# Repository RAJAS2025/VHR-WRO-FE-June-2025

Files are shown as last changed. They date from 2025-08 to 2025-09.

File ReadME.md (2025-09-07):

This repository contains the documentation for Team VHR team's robot for the 2025 World Robot Olympiad Future Engineers competition. 

## Table of Contents
* [The Team](#the-team-)
* [The Challenge](#the-challenge-)
* [Photos of our Robot](#photos-of-our-robot)
* [Performance Video](#video)
* [Mobility Management](#mobility-management-)
  * [Chassis](#chassis)
  * [Spur Gear](#spur-gear)
  * [Differential Gear](#differential-gear)
  * [Steering Connecting Bar](#steering-connecting-bar)
  * [Wheel Holders](#wheel-holdersleft-and-right)
  * [Distance Sensor Holders](#distance-sensor-holder)
  * [Assembly of Chassis](#assembly-of-chassis)
  * [Motors](#motors)
  * [Drivetrain and Chassis Design](#new-drivetrain--chassis-design)
    * [Old Drivetrain and Chassis Design](#old-drivetrain--chassis-design)
    * [Differences in Old and New Chassis](#differences-between-new-and-old-chassis)
    * [New Robot Steering](#new-robot-steering)
    * [Old Robot Steering](#old-robot-steering)
    * [Car Component Placement](#car-component-placement) 
* [Power and Sense Management](#power-and-sense-management-)
  * [Controller](#controller)
  * [Battery](#battery)
  * [Sensing](#sensing)
  * [Gyro](#mpu-6050-3-axis-accelerometer--gyroscope)
  * [Camera](#huskylens-ai-vision-sensor)
  * [Schematics](#schematics-)
  * [Energy Consumption Breakdown](#energy-consumption-breakdown)
  * [Circuit Diagram](#circuit-diagram)
* [Obstacle Management](#obstacle-management-)
  * [Open Challenge Strategy and Code Explanation](#open-challenge-strategy-and-code-explanation)
  * [Obstacle Challenge Strategy and Code Explanation](#obstacle-challenge-strategy-and-code-explanation)
    * [Obstacle Challenge Turning Logic](#obstacle-challenge-turning-logic)
    * [Dodging Blocks](#dodging-blocks)
      * [Block Detection](#block-detection-huskylens)
      * [Adaptive Speed Control](#adaptive-speed-control)
      * [Block Dodging Algorithm](#block-dodging-algorithm)
      * [Steering and Gyro Function](#steering--wall-following-forward-function-obstacle)
    * [Parallel Parking](#parallel-parking)
* [Robot Assembly Guide](#assembly-guide)
* [Cost Report](#cost-report)
  * [Parts Cost](#part-cost)
  * [Parts BOM](#parts-bill-of-materials-bom)
* [Special Thanks](#special-thanks)

---

# The Team 

### Team photo
 
<br>
(Harshad, Vishnu, Rajas)

<br>

### Harshad Mahajan

<b>Age:</b> 15

<b>High School:</b> John Fraser Secondary School

<b>Description:</b> Hi! I’m Harshad. This is my first season in WRO. Last year I took part in the Zone_01 category, and this year I wanted to challenge myself with something new. I’m interested in coding, building robots, and exploring creative ideas. I also enjoy sports and traveling.

---

### Vishnu Jayakumar

<b>Age:</b> 15

<b>High School:</b> John Fraser Secondary School

<b>Description:</b> Hello! I’m Vishnu. This is my third season in WRO and my first time competing in the Future Engineers category, after two seasons in WRO Junior. I’m passionate about robotics, electronics, and exploring new technologies, but I also enjoy basketball, math, and spending time with friends.

---

### Rajas Salunke

<b>Age:</b> 16

<b>High School:</b> Fletchers Meadows Secondary School

<b>Description:</b> Hello! I’m Rajas Salunke. This is my second season in WRO and my first in the Future Engineers category, after previously competing in WRO Junior. I’m passionate about building circuits and rockets, and I also enjoy hockey and calisthenics.

---

## The Challenge 

The **[WRO 2025 Future Engineers](https://wro-association.org/)** challenge is all about building an autonomous car that can adapt to a racetrack which changes every round. Instead of just speed, the focus is on control and problem-solving: the car needs to handle obstacles placed at random and also pull off a precise parallel park. It’s a mix of engineering and strategy, where teams combine sensors, algorithms, and creative design to make their car both smart and reliable.

This challenge emphasizes all aspects of the engineering process, including:
- **Movement:** Designing the vehicle to move efficiently and smoothly.
- **Obstacle Navigation:** Programming the car to detect and handle traffic markers within the rules.les.
- **Documentation:** Recording design decisions, progress, and collaborative work in a public GitHub repository.

Points are awarded based on how well teams perform in the challenge rounds, the thoroughness of their engineering documentation, and the creativity and reliability of their solutions. The aim is to inspire learning in STEM through hands-on robotics, collaborative teamwork, and inventive problem-solving.

To learn more about the challenge, click [here](https://wro-association.org/wp-content/uploads/WRO-2025-Future-Engineers-Self-Driving-Cars-General-Rules.pdf).

---

# Photos of our Robot

|  |  | 
| :--: | :--: |
| *Front* | *Back* |
|  |  | 
| *Left* | *Right* |
|  |  | 
| *Top* | *Bottom* |

---

# Video
Here is the link to our Obstacle Challenge: https://youtu.be/RuCk_0WW9Mc
<br>
Here is the link to our Open Challenge: https://youtu.be/YiaeHu-xXsg

--- 

# Mobility Management 

## Chassis

Our chassis is a fully custom-designed base, modeled in SolidWorks to create a compact and efficient structure optimized for sharp servo steering. On top of the chassis, we mounted our PCB, which holds the main electronics and three laser distance sensors—one at the front and one on each side—allowing the robot to sense walls and obstacles accurately. The motor is positioned beneath the PCB in a dedicated motor holder and drives a spur gear that connects to a reinforced LEGO differential, forming a robust drivetrain.

The front steering is designed for sharp, precise turns, giving the robot the ability to navigate tight corners and avoid obstacles efficiently. The chassis layout also ensures that the weight of the sensors and electronics is balanced over the drivetrain, improving stability and traction during high-speed maneuvers.

### Potential Chassis Improvements
An improvement we could make to our chassis is lowering the center of gravity even further. A lower center of gravity keeps the car’s weight closer to the ground, which improves stability and allows for quicker, more accurate steering at higher speeds. With reduced body roll, the tires maintain stronger grip on the road, giving the driver greater precision and control. As a result, the car feels more responsive during sharp turns, lane changes, and fast cornering.



### Spur Gear

To transfer power from the 6V motors to the modified LEGO differential, we designed and 3D-printed a 36-tooth spur gear that fits the motor’s 3mm D-shaped shaft and meshes precisely with the LEGO axle system. Using a 36-tooth input gear paired with a 24-tooth output gear, we geared the drivetrain for higher speed while taking advantage of the motor’s high torque and low RPM. This gear ensures smooth and efficient power transfer, providing consistent wheel rotation even under load.



### Differential Gear

The LEGO differential was imported from an online CAD model into SolidWorks and slightly reinforced to improve durability. Extra material was added around the mounting holes, and the differential was adapted to fit our custom chassis. These modifications maintain smooth power transfer to the wheels under high-torque operation, while reducing stress on the mounting points and improving overall reliability during obstacle navigation.



### Steering Connecting Bar

The steering connecting bar is a compact, custom-designed link optimized for our sharp servo steering system. Modeled in SolidWorks, it features recessed screw inlets for better grip and durability, ensuring a secure connection between steering components. Its lightweight design minimizes additional load while transferring motion smoothly, allowing the front wheels to respond precisely to steering commands even during tight turns.

 

### Wheel Holders(Left and Right)
The wheel holder was custom-designed in SolidWorks for our compact steering system. The extended cylinder secures a bearing for smooth tire rotation, while the smaller hole connects to the steering bar and the larger hole mounts to the chassis base.

 

### Distance Sensor Holder

The distance sensor holder combines a custom-made 4M LEGO beam with a secure TinkerCAD-designed mount to keep the TOF sensor rigid and stable. This eliminates vibration or shifting during operation, ensuring accurate and consistent sensor readings. The LEGO integration allows for easy attachment to the chassis while maintaining a locked position, supporting reliable obstacle detection and wall-following maneuvers.



### Assembly of Chassis

ezgif com-video-to-gif-converter (1)

## Motors

### 24mm Brushless DC Gear Motor
The robot's forward and backward propulsion is provided by a 24mm brushless DC gear motor. This motor was chosen for its ideal balance of high speed and torque. The brushless design makes it highly efficient, durable, and provides a smooth, consistent power delivery. This motor is the core of the drivetrain, ensuring reliable and powerful movement throughout the competition.



Here are the specifications: [Motor Specifications](https://drive.google.com/file/d/1moiPKcTiO8_0Bga1mJdIX5mgfcUgAj7J/view?usp=drive_link)

### Miuzei MG90S 9G Micro Servo Motor
The robot's steering mechanism is controlled by a Miuzei MG90S 9G Micro Servo Motor. A servo is a specialized motor designed for precise angular control rather than continuous rotation. This particular model was chosen for its metal gear construction, which offers greater durability and higher torque than plastic gear versions. The servo's ability to hold a specific angle is what allows the robot to make precise steering adjustments and navigate tight corners effectively.



Here are the specifications: [Servo Specifications](https://drive.google.com/file/d/1ZQCr9s1xJsN8NOYWgczae_1dq8hoC7bo/view?usp=drive_link)

## New Drivetrain & Chassis Design

Our robot is a four-wheeled vehicle that uses a **rear-wheel drive with sharp front-wheel servo steering**. The chassis was custom-modeled in SolidWorks for a compact, lightweight structure that minimizes complexity while maximizing reliability. By separating the steering system from the drivetrain, we avoided issues with spacing and ensured that the steering servo and the drive motors operate independently without interference. This gave us two possible configurations: front-wheel drive with rear steering or rear-wheel drive with front steering.  

We chose the **rear-wheel drive with front steering** configuration because it provides several advantages:

| Rear-Wheel Drive | Front-Wheel Drive |
| --- | --- |
|  |  |
| **Why we chose rear-wheel drive:** <br><br>- **More precise steering**, since the front wheels focus only on steering. <br>- **Balanced handling**, with weight distributed between front and rear. <br>- **No torque steer**, unlike front-wheel drive systems. <br>- **Stronger traction under acceleration**, as weight shifts to the rear drive wheels. <br>- **Better power handling**, making it suitable for higher torque motors. <br>- **Familiar control response**, matching our previous experience with other rear-driven LEGO robots. | **Why we avoided front-wheel drive:** <br><br>- Steering is less precise because the wheels also handle power delivery. <br>- Can cause **torque steer**, pulling the robot off-course under acceleration. <br>- Reduced traction at the rear wheels, especially when weight shifts forward during braking. <br>- Harder to balance power and steering without interference. <br>- Less efficient for handling higher torque loads. |

Overall, the **rear-wheel drive with front steering** configuration gave us the best balance of control, traction, and reliability. It allowed us to maximize precision while keeping the drivetrain simple and effective for competition.

---

The drivetrain works by transferring power from the rear motors into a 36-tooth spur gear that meshes with a 24-tooth gear, creating a 1.5:1 gear ratio. This gearing choice slightly increases speed while still maintaining enough torque to handle obstacles. From there, power flows into the differential gear, which splits torque between the two rear wheels so they can spin at different speeds during turns. This prevents skidding, reduces stress on the drivetrain, and keeps the robot’s motion smooth. The differential outputs directly to the rear wheels, giving strong and reliable traction. Meanwhile, the front wheels are connected to a servo motor that independently controls steering. Because the steering and drivetrain are separate, the robot achieves sharp, responsive turns without being affected by torque from the drive system.

## Old Drivetrain & Chassis Design

Our old robot also used a rear-wheel drive system with the same advantages. However, it was built mostly from LEGO pieces, making it bulkier and less optimized. The drivetrain design placed the motor vertically at the back, which consumed a lot of space.

| Back Photo of Motor | Side Photo of Motor |
| --- | --- |
|  |  |

## Differences between New and Old Chassis

In our new robot, the motor case is positioned beneath the battery holder, saving significant space and allowing for a more compact design. The gearing layout has also been updated: the new robot uses a side-to-side gearing configuration due to the use of spur gears, whereas the old robot had a downward setup due to the use of bevel gears. The old chassis was designed with space for gearing down to achieve more torque, while the new chassis supports either a 1:1 ratio (30-tooth spur to 30-tooth differential) or our current setup with a 36-tooth spur and 24-tooth differential. Additionally, the steering base in the new chassis is smaller and more compact, in contrast to the old design where the steering width spanned the entire chassis.

| Spur Gear View of Chassis | Differential Gear View of Chassis |
| --- | --- |
|  |  |

## New Robot Steering

Our steering system uses a four-bar linkage with free-spinning wheels on each side. A servo motor with an arm drives the four-bar, changing the wheel angles to steer the vehicle. This setup is lightweight, efficient, and easy to implement with minimal components.

The steering is managed by a Miuzei MG90S micro servo motor, which provides precise angular control. A standard servo arm drives a four-bar linkage, with free-spinning wheels on each side made from a bearing fitted with a tire. Each wheel is secured using a custom attachment that connects directly to the bearing. This lightweight and durable setup ensures quick, precise steering response, enabling the robot to execute sharp turns and navigate obstacles effectively. To save space, our steering is mounted in a reversed configuration: the four-bar sits behind the servo’s output, and the arm operates in the opposite direction.

ezgif com-speed (1)

## Old Robot Steering
In our previous robot, we employed the same steering concept, but the system was configured in a forward layout and was significantly larger and wider. The servo arm and mount were 3D printed as a single piece, featuring a LEGO axle–shaped cross hole that rotated in sync with the servo. Unlike the new design, the four-bar linkage was not 3D printed; it was constructed by connecting two LEGO beams with a LEGO wheel mounted on each side.

| Four-Bar Steering Mechanism |
| --------------------------- |
|  |

## Car Component Placement

The main chassis serves as the foundation of the car, housing most of the core components. On top of this base, additional parts such as VEX pieces, LEGO elements, and custom 3D-printed mounts are integrated to securely attach and support each component. More details about each specific electrical component can be found in power and sense management. 

| Part | Description | Image |
| --- | --- | --- |
| TOF Distance Sensors | • **Two-beam setup** for mounting<br>• **Double-sided beam** secured with two VEX star-drive screws<br>• **LEGO beam + frame** attached below VEX beam<br>• Frame offers **multiple connection points**<br>• TOF sensors mounted using **LEGO beams on their side**<br>• Allows **easy adjustment** and **quick fixes**<br>• Maintains overall **stability** |  |
| Husky Lens Camera | • Mounted on **two VEX standoffs**<br>• Standoffs fastened to **LEGO beams** with VEX screws<br>• Camera secured with **two M3 screws** on top beam<br>• Chosen over **3D-printed bracket** for flexibility<br>• **Adjustable height** by swapping standoffs<br>• Provides **rigidity and durability** |  |
| Battery | • Placed at **center of chassis CAD**<br>• **Dedicated slot** sized for battery fit<br>• **PCB mounted above** for short, direct connections<br>• Prevents **wire tangling**<br>• **Front cutout** allows space for servo motor integration |  |
| PCB | • Located **above battery slot**<br>• Space designed for **PCB with sensor ports**<br>• **Clear sides** for neat wire management<br>• **Rear hole** provides access to power button<br>• Supports clean and efficient wiring layout |  |
| Camera Lens | • Located **on camera**<br>• Added to widen camera view and see more blocks |  |

# Power and Sense Management   

## Controller

The robot uses an ESP32 microcontroller for fast processing and built-in Wi-Fi/Bluetooth. It handles everything from sensor input to motor control and wireless communication without slowing down. Its small size fits easily in the chassis, and low power use helps extend battery life — perfect for competition.

An image of a ESP32 controller

## Battery

The robot is powered by two 6-volt NiMH (Nickel-Metal Hydride) battery packs. We chose these batteries for their high current output, which is essential for reliably running all the electronics, including the motors, without performance drops. Their use also ensures the robot has enough capacity for longer operation periods, a key advantage during competition.

As rechargeable batteries, they provide a cost-effective and time-saving solution, as they don't need to be replaced after every use. Their compact size allows them to fit neatly inside the robot's chassis, which helps in maintaining a balanced and low-profile design.

An image of a NiMH battery pack

## Sensing

### VL53L0X Time-of-Flight (ToF) Distance Sensors

The robot uses three VL53L0X Time-of-Flight (ToF) distance sensors to measure the distance to surrounding objects. These sensors work by emitting a laser pulse and calculating the time it takes for the light to reflect back, providing highly accurate and reliable distance measurements in millimeters. The three sensors are strategically placed on the robot to provide multi-directional awareness for obstacle avoidance and maintaining a consistent distance from the walls. They are the primary tool for the robot's navigation on the track.

An image of a VL53L0X ToF distance sensor

### MPU-6050 3-Axis Accelerometer & Gyroscope

The MPU-6050 is used to monitor the robot's orientation and heading. The gyroscope provides real-time data on the robot's yaw, pitch, and roll. The robot primarily uses the yaw axis to track its heading and maintain accurate directional control. Before each use, the gyro is calibrated to ensure precision, and a starting reference angle is set to 0. This allows the robot to consistently track its orientation and make precise turns, such as a 90-degree turn, by adjusting the offset relative to its starting position. This sensor is crucial for ensuring the robot drives in a straight line and turns accurately.

An image of a MPU-6050 gyro sensor

### HuskyLens AI Vision Sensor
The HuskyLens is a powerful AI vision sensor that provides the robot with the ability to "see" and identify objects. It is pre-trained to recognize colors and objects, which is a key part of your strategy for the Obstacle Challenge. The robot uses the HuskyLens for several key functions:

- **Color Recognition:** It is trained to detect specific colors like red and green for identifying traffic blocks, pink for the parallel parking markers, and blue and orange lines to turn.

- **Object Positioning:** The sensor provides the x and y coordinates of the detected objects, which are directly used by the program to guide the robot's movements.
This sensor allows the robot to perform complex tasks like avoiding obstacles and executing precise maneuvers such as parallel parking.

An image of a Huskylens AI vision sensor

---

# Schematics 

This schematic provides a clear overview of the robot's electronic design. It shows how a central ESP32 microcontroller manages various sensors and motors, enabling autonomous navigation and obstacle avoidance. The design is modular, with a focus on efficient communication and power management.

A schematic of the robot's electronic components and connections

### Power Management
The robot's power is supplied by a 6V battery pack, which connects at CN1. This power is distributed to all components in two ways. A voltage regulator (U8) steps down the 6V to a stable 3.3V to safely power the ESP32 and other sensitive electronics. The 6V supply is also used directly to power the motors and servo, as they require higher voltage and current.

### Motors
The Miuzei MG90S 9G Micro Servo Motor (S1) connects to pin D32 on the board for its control signal. The 24mm Brushless DC Gear Motor connects to the board via its motor driver (not explicitly shown) to a GPIO pin for control. Both motors are powered by the external 6V supply

### Sensors

- **VL53L0X ToF Lidar Sensors (U2, U3, U4):** The three VL53L0X Lidar sensors (U2, U3, U4) connect to the board's I2C pins (SDA/SCL) via an I2C Multiplexer (U7).

- **I2C Multiplexer (U7) & I2C Expander (U5):** To manage the three Lidar sensors on a single I2C bus, an I2C Multiplexer is used to allow the microcontroller to communicate with each sensor individually. An I2C Expander is also included to provide additional I2C communication lines for other devices.

- **HuskyLens (UB):** The HuskyLens (UB) connects to the board's serial communication pins (RXD2/TXD2) to send data back and forth.

## Energy Consumption Breakdown

### Baseline (no motors)
- ESP32 + HuskyLens + MPU6050 + 3× ToF  
  - 120 + 230 = 350 mA  
  - 350 + 4 = 354 mA  
  - 354 + 60 = **414 mA**

### Typical Total (with motors + servo)
- Baseline: 414 mA  
- + DC motor (typical): +450 mA → 864 mA  
- + Servo (typical): +70 mA → **934 mA**

### Peak Load
- ESP32 peak: 260 mA  
- HuskyLens peak: 300 mA → 560 mA  
- + MPU6050: +4 mA → 564 mA  
- + ToF peaks: +120 mA → 684 mA  
- + Motor nominal: +450 mA → 1,134 mA  
- + Servo peak (70–140 mA): → **~1,204 mA**

### Worst-Case (stall currents)
- DC motor stall: 3× nominal → 450 × 3 = 1,350 mA  
- Servo stall: 2× → 70 × 2 = 140 mA  
- Non-motor peak subtotal: 684 mA  
- 684 + 1,350 + 140 = **≈ 2,174 mA (~2.17 A)**

---

**Summary:**  
- Typical draw ≈ **934 mA**  
- Peak ≈ **1.2 A**  
- Worst-case transient ≈ **2.2 A**

---

# Obstacle Management 

## Open Challenge: Strategy and Code Explanation

This program controls the robot using TOF sensors and a gyro to navigate by following the outer wall. When the robot detects a wall ahead, it chooses the clearer side by comparing right and left values, and stores it in side. From that point on, the robot consistently follows the chosen outer wall, using TOF readings and gyro correction to stay aligned. Because the outer wall distance is always fixed, this method remains reliable even if interior walls shift or move. A turn count tracks progress through the maze, and once it reaches 12, the robot stops wall-following and drives straight to the finish using gyro-based control.

| Straight Movement | Turning |
| --- | --- |
|  |  |

| Open Challenge Flowchart |
| ------------------------ |
|  |

### Robot Motion Control (Open)

This part of the repository contains control laws for straight driving using gyro correction and wall-following behaviors using TOF sensor + gyro fusion.  

#### Straight Driving (forward)

The `forward()` function maintains straight-line motion by applying gyro-based steering correction.
```ino
// Move forward while correcting steering based on gyro
void forward(float g) {
  angle = (int)(0.8 * (g - (offsetangle))); // Steering correction
  int pos = 95 - angle;                     // Servo position
  myservo.write(pos);
  motor.run_motor(1, 80);                  // Run motor forward
}
```
##### Breakdown
- **Gyro Correction** → Adjusts steering based on yaw error relative to `offsetangle`.  
- **Steering Command** → Servo centered at 95, shifted by correction.  
- **Motor Drive** → Moves forward at a fixed speed (80).  

#### Right Wall Following (rforwardwall)

The `rforwardwall()` function follows the right wall by combining TOF distance sensing and gyro correction.
```ino
void rforwardwall(float g, int d) {
float wallval = 0.08 * (d - 350); // Correction based on distance
angle = int(0.6 * (g - (offsetangle + wallval)));
angle = constrain(angle, -10, 10);
int pos = 95 - angle;
pos = constrain(pos, 80, 110);
myservo.write(pos);
motor.run_motor(1, 100);
}`
```
##### Breakdown
- **Wall Following** → Calculates offset `wallval` from right wall distance (`d`).  
- **Gyro Correction** → Combines yaw angle and distance offset for stability.  
- **Steering Command** → Servo constrained between 80 and 110 for safer correction.  
- **Motor Drive** → Forward motion at higher speed (100).  

---

#### Left Wall Following (lforwardwall)

The `lforwardwall()` function mirrors the right wall following, but uses the left wall as reference.
```ino
void lforwardwall(float g, int d) {
float wallval = 0.08 * (d - 400); // Correction based on distance
angle = int(0.6 * (g - (offsetangle - wallval)));
angle = constrain(angle, -10, 10);
int pos = 95 - angle;
pos = constrain(pos, 80, 110);
myservo.write(pos);
motor.run_motor(1, 100);
}
```
##### Breakdown
- **Wall Following** → Calculates offset `wallval` from left wall distance (`d`).  
- **Gyro Correction** → Uses yaw angle adjusted with left-side offset.  
- **Steering Command** → Servo constrained between 80 and 110 to limit oscillations.  
- **Motor Drive** → Forward motion at higher speed (100).  

---

## Obstacle Challenge: Strategy and Code Explanation

Our approach focuses on maintaining precise control and adaptability while navigating the course. The robot will use gyro-based line following to stay straight on the track, supported by distance sensors to prevent collisions on the walls. When encountering a block, the robot will slow down and maneuver around it before continuing forward once the path is clear. Turns will be guided by the camera system, which identifies the blue and orange lines on the mat to ensure consistent and accurate direction changes. Throughout the run, we will track progress by counting completed turns, allowing the robot to recognize when the course has been finished. This plan balances speed, accuracy, and reliability to effectively handle obstacles and complete the challenge.

| Red Block Movement | Green Block Movement |
| --- | --- |
|  |  |

| Obstacle Challenge Flowchart |
| ------------------------ |
|  |

<br>

### Obstacle Challenge Turning Logic

In the **Obstacle Challenge**, our robot had to detect the blue and orange lines on the playing field and update its gyro heading to execute precise turning maneuvers.  
We implemented **three distinct turning logics** depending on what obstacle is detected ahead:

---

#### If we see a Green Block → Do Green Turning Logic  

<table>
<tr>
<td width="40%">
Green Turning<br>
<em>Figure 1: Green turning logic – go forward, then turn to go around the block.</em>
</td>
<td width="60%">
<ul>
<li>The robot first drives forward past the green block.</li>
<li>Once the block is cleared, it performs a controlled turn using the updated gyro heading.</li>
<li>This ensures the robot smoothly goes around the block without losing alignment.</li>
</ul>
</td>
</tr>
</table>

```ino
else if (gp == true) { 
    // move forward while ignoring walls
    while (i < 450){ forward(yaw, 0, 1000, 1000); }
    // keep moving until safe
    while (frontdist > 350){ forward(yaw, 0, 1000, 1000); }
    // then perform controlled turn
    target = abs(offsetangle) + 70;
    while (yaw < target) { myservo.write(135); }
}
```
---

#### If we see a Red Block → Do Red Turning Logic  

<table>
<tr>
<td width="40%">
Red Turning<br>
<em>Figure 2: Red turning logic – sharp turn around the red block.</em>
</td>
<td width="60%">
<ul>
<li>The robot immediately executes a <b>sharp turn</b> as soon as it detects the red block.</li>
<li>This quick maneuver avoids collision while still keeping the robot on course.</li>
<li>The gyro is then used to realign before moving forward again.</li>
</ul>
</td>
</tr>
</table>

```ino
if (rp == true) {
    motor.run_motor(1, 45);
    if (rightdist < 300) {
        target = abs(offsetangle) + 40;
        while (yaw < target) { myservo.write(115); }
    } else {
        target = abs(offsetangle) + 38;
        while (yaw < target) { myservo.write(135); }
    }
}
```

---

#### If No Block is Detected → Do No Block Turning Logic  

<table>
<tr>
<td width="40%">
No Block Turning<br>
<em>Figure 3: Final turning logic – align to the center when no block is detected.</em>
</td>
<td width="60%">
<ul>
<li>The robot drives forward into the middle of the field.</li>
<li>It then performs a turn and reverses slightly.</li>
<li>The backward movement helps re-center the robot in the next section for better alignment.</li>
</ul>
</td>
</tr>
</table>

```ino
else {
    while (frontdist > 450) { forward(yaw, 0, 1000, 1000); }
    target = abs(offsetangle) + 75;
    while (yaw < target) { myservo.write(145); }
    motor.stop_motor();
    myservo.write(95);
    motor.run_motor(0, 55);
    delay(750);  // reverse slightly
    motor.stop_motor();
}
```

---
By combining **line detection (blue/orange lines)** with **gyro updates**, the robot could reliably identify its position and apply the correct turning strategy. This adaptive logic ensured consistent navigation through different obstacle configurations.

### Dodging Blocks

These are the following steps we take to dodge a block and generally, just have the robot run through the laps.

- Detect and identify colored blocks and lines (Red, Green, Blue, Orange, Pink).  
- Slow down automatically as it approaches obstacles.  
- Dodge blocks smoothly by adjusting steering.  
- Maintain stable heading while wall-following.

---

#### Block Detection (HuskyLens)

The **HuskyLens** provides:

- `xCenter` → horizontal position of the block.  
- `yCenter` → vertical position (bigger = closer).  
- `width / height` → block size in pixels.  

In the `camread()` function:
- Each color activates a flag (`rp`, `gp`, `bl`, `ol`, `pw`).  
- Positions `(x, y)` are stored.  
- The **closest block** is the one with the **largest yCenter** or when comparing if green and red is closer, the **largest area** taken on screen.

---

#### Adaptive Speed Control

Motor speed decreases as blocks get closer:

- `curr_y` = `yCenter` of closest block.  
- Larger `y` → Closer block → Slower motor.  
- Minimum speed of **50** is enforced.
- The full speed algorithm looks like this:
  ```ino
  motorSpeed = baseSpeed - int((0.2 * curr_y));  //70 Base Speed and 0.2 slowing down constant
  if (by > 100 && side == 1) {
   motorSpeed = 50;
  } else if (oy > 100 && side == 2) {
   motorSpeed = 50;`
  }
  if (motorSpeed < 50) {
   motorSpeed = 50;
  }
  ```
- The additional logic is for slowing down when seeing the blue or orange line depending on which side we drive
  If you want to visualize our function, here is a graph of our speed deceleration according to camera y:

  Green Turning<br>
  
---
#### Block Dodging Algorithm

Each block influences the steering correction.  

Example: **Red Block (forces left dodge)**

- **Red Block Code :**  `red = 0.0035 * (20 - rx) * ry;` (RED proportional is slightly higher than green because of the green being brighter and having higher Ycenter value)
- Formula = `(desired_x - current_x) * distance_y`.  
- Far block (small y) → small correction.  
- Close block (large y) → bigger correction.

The combined correction is:

This value is passed into the steering algorithm.

Below is a 3d graph model of how our function scales to go around the block.

https://www.desmos.com/3d/tnomdtba0m

---

#### Steering & Wall Following (`forward()` Function) (Obstacle)

Main control law that combines wall-following, block avoidance, and gyro correction:

```ino
if (lwd < 350) lwallval = 0.035 * (lwd - 350);
else lwallval = 0;

float kp = 0.35;
int angle;

// Correction logic
if (distance) {
    angle = (int)(kp * (g - (offsetangle - block + rwallval - lwallval)));
} else {
    if (side == 1)
        angle = (int)(kp * (g - (offsetangle - block - lwallval)));
    else
        angle = (int)(kp * (g - (offsetangle - block + rwallval)));
}

// Servo steering
int pos = 95 - angle;
pos = constrain(pos, 65, 115);
myservo.write(pos);

// Motor forward with adaptive speed
motor.run_motor(1, motorSpeed);
```
##### Breakdown of `forward()`:
- **Wall Following** → Keeps robot centered using TOF sensors (`rwd`, `lwd`).  
- **Block Avoidance** → Adds correction (`block = target_x`) from HuskyLens.  
- **Gyro Correction** → Maintains stable heading with IMU yaw.  
- **Steering Command** → Servo angle constrained between `65` and `115`.  
- **Motor Drive** → Runs forward at adaptive speed.  

### System Summary

- **Closest Block** = Block with highest `yCenter`.  
- **Speed Control** = Proportional to `yCenter` (closer = slower).  
- **Dodging** = Steering correction from block offset.  
- **Navigation** = Combination of wall following, block avoidance, and gyro correction.  

### Future Improvements

- Tune coefficients for better performance.  
- Add PID-based velocity control for smoother deceleration.

---

## Parallel Parking

### 1. Initial Right Turn

- Robot drives while steering hard right.
- Keeps turning until the gyro yaw reaches the target angle.
- Stops and centers steering.

### 2. Short Backward Movement

- Moves backward for about 1 second.
- Stops to reposition.

### 3. Forward Until Front Obstacle

- Drives straight forward.
- Keeps going until the front sensor detects something closer than 20 cm.
- Stops and pauses briefly.

### 4. Second Right Turn

- Makes another right turn at lower speed.
- Uses gyro to measure the angle.
- Stops and updates its internal offset angle.

### 5. Forward Toward Wall

- Moves forward while tracking the left wall.
- Uses both the gyro and left sensor to stay aligned.
- Stops once the front sensor detects an obstacle within 30 cm.

### 6. Small Right Correction

- Turns slightly right to refine alignment.
- Stops once the target yaw is reached.

### 7. Straightening (Left Turn)

- Makes a small left turn to straighten the robot.
- Centers the steering afterward.

### 8. Forward Until Pink Wall

- Drives forward briefly, then continues until the left sensor detects a wall within 20 cm.
- Stops when close enough.

### 9. Decision Point

- Robot checks the left distance:
- If < 30 cm → goes to Branch A.
- If ≥ 30 cm → goes to Branch B.

### Branch A – Left Wall Close

- Turns right until yaw target reached.
- Centers steering.
- Moves forward a short distance.
- Reverses while turning left to straighten.
- Stops, centers steering, and remains parked.

### Branch B – Left Wall Far

- Reverses into a wider right turn.
- Stops and centers steering.
- Moves forward briefly.
- Backs up slightly.
- Makes a small reverse correction turn.
- Turns left until aligned.
- Centers steering and remains parked.

### Summary of Parking

- Gyro: controls turning and orientation.
- Servo: steers right/left.
- Front sensor: stops robot when approaching obstacles.
- Left sensor: helps align with the wall and decide parking branch.

The sequence of turns + forward/reverse moves guides the robot into its parking spot. To examine specific lines of code, locate the `park()` clockwise run function at the bottom of the obstacle challenge code and review the accompanying comments.

---

# Assembly Guide

Here is our video for the assembly proccess of our robot: https://youtu.be/ncnzsIrPrJM

---

# Cost Report

## Part Cost
| Part Name | Product | Price |
| --- | --- | --- |
| Battery | [`NiMH Battery Packs`](https://www.amazon.ca/melasta-Controller-Transmitter-Batteries-Rechargeable/dp/B08H1VGPTQ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) | $26.59 |
| Drive Motor | [`24mm Brushless DC Gear Motor – 6V 175RPM`](https://ca.robotshop.com/products/e-s-motor-24mm-brushless-dc-gear-motor-6v-175rpm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) | $17.43 | 
| Servo Motor| [`Miuzei MG90S 9G Micro Servo Motor`](https://www.amazon.ca/Miuzei-MG90S-Servo-Helicopter-Arduino/dp/B0BWJ4RKGV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) | $8.49 |
| Distance Sensors | [`VL53L0X V2 Distance Sensors`](https://www.adafruit.com/product/3317?srsltid=AfmBOoo2bXDFNLP4muxH_TJ6E1TMgPw9tgMk8_leCCFIUnABXe_XegRi) | $14.95 |
| Gyro | [`MPU-6050 3-Axis Accelerometer & Gyroscope: LINK NEEDED`](https://carisma-shop.com/products/gt24-alum-motor-mount) | $12.99 |
| Camera | [`Huskylens`](https://ca.robotshop.com/products/gravity-huskylens-ai-machine-vision-sensor-w-silicone-case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) | $83.43 |
| Camera Lens | [`Fish Eye Lens`](https://www.amazon.ca/dp/B00FTSG35E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)

## Miscallaneous 

- **Filament Used:** PLA, CF
- **Wires:** Custom made wires made similar to lego wires
- **Lego Pieces:** Beams, Double-sided Beams, Pegs, etc (In the front of car)
- **Vex Pieces:** Starhead screws, Standoffs

## Parts Bill Of Materials (BOM)
| Part Name | Quantity |
| ---| --- |
| NiMH Battery Packs | 2 |
| VL53L0X V2 Distance Sensors | 3 |
| ESP32 | 1 |
| 24mm Brushless DC Gear Motor – 6V 175RPM | 1 |
| Miuzei MG90S 9G Micro Servo Motor | 1 |
| MPU-6050 3-Axis Accelerometer & Gyroscope | 1 |
| HuskyLens | 1 |

**Total Car Cost: $193.78 CAD**

# Special Thanks

## Coach Vikram
Coach Vikram is super passionate about mixing electronics and robotics, and you can totally feel that whenever he talks. He’s always cheerful and positive, which makes practice fun even when things get tough. He never just gave us the code or held our hands; instead, he kept asking us questions so we’d figure it out ourselves. That way, he got us ready for this new competition and made us more confident along the way.

## Akhil
Akhil is a 2nd year engineering student at Carlton University, and he’s the kind of guy who loves digging into code and building libraries from scratch. He’s calm and focused, always ready to sit down and figure out the tricky parts without rushing. Whenever we got stuck, he would explain things in a simple way and show us how to build tools that actually make our work easier. He helped us to create our libraries, when we had no experience with C+ and Arduino.

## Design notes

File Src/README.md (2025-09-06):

Source Code Documentation
==== 

This directory contains all of the software needed to operate our robot. It explains the programming language, tools, organization, and functionality of the code that drives and integrates our sensors, actuators, and control systems.

## Software and Language
Our robot is programmed using the Arduino IDE with code written for the ESP32 microcontroller. The programming is done in C++, with libraries that interface directly with our hardware components. Compiling and uploading the code is a simple process using the Arduino IDE’s Verify and Upload buttons, which automatically compile the code and flash it to the ESP32.

## Libraries Used

The following libraries are utilized to interface with our robot’s electronics:
SMotor.h – Controls the DC motor driver for robot movement.

ESP32Servo.h – Used for steering control through a servo motor.

ZebraTOF.h – Interfaces with the Time-of-Flight (ToF) distance sensors for precise ranging.

ZebraGyro.h – Interfaces with the gyroscope for angular velocity and orientation measurement.

Wire.h – Provides I2C communication for sensor connections.

HUSKYLENS.h – Interfaces with the HuskyLens AI vision sensor for color/obstacle detection.

## Organization of Code

Our code is structured into initialization, setup, and control logic, following Object-Oriented Programming (OOP) conventions wherever possible. Sensors and actuators are abstracted into class instances for modularity.
The program is split into two main sections:
Setup() – Initializes all hardware, calibrates sensors, configures communication protocols, and waits for the start signal via the button.

Loop() – Contains the continuous control logic for navigation, obstacle avoidance, wall following, and object interaction.

## Key Components

Motor Control (SMotor Class)
  Controls the DC driving motor using the run_motor and stop_motor functions.

  Uses PWM signals to regulate motor speed.

  Example: motor.run_motor(1, 55); drives the robot forward at speed 55.

## Servo Steering (ESP32Servo)

A servo motor mounted on the front provides steering.

Controlled via PWM using myservo.write(angle).

Range is approximately 45° (left) to 135° (right) with 95° as straight alignment.

## Distance Sensors (ZebraTOF)

Three Time-of-Flight (ToF) sensors:

Front sensor (collision avoidance, forward distance).

Left sensor (used for wall following).

Right sensor (used for wall following).

Example usage:

` int frontdist = front.readDistance1(); `
`rightdist = constrain(right.readDistance1(), 0, 1200);`
`leftdist = constrain(left.readDistance1(), 0, 1200);'`

## Gyroscope (ZebraGyro)

Provides yaw angle feedback for heading correction.

Used for gyro-based turning and to maintain straight-line movement.

Example:

`gyro.update();`
`yaw = gyro.getYaw();`

## Camera (HuskyLens AI Vision Sensor)

Detects colored objects (red, green, pink, blue, orange).

Communicates over UART (TX/RX pins on ESP32).

Provides bounding box data `(x, y, width, height, area)` for detected objects.

Used for color-based navigation and obstacle identification.

## Navigation and Control Logic
Startup Phase

Robot initializes sensors and waits for the start button press.

Determines initial side (left/right wall) based on ToF distance readings.

Gyro-Based Turning

Uses gyroscope readings to rotate precisely to target angles.

Example:

 `while (yaw > (target * -1)) {
    gyro.update();
    yaw = gyro.getYaw();
    myservo.write(45);
}`

Wall Following

Uses ToF sensors to maintain a safe distance from walls.

Steering corrections are applied proportionally:

 `err = 20.0 - rightdist;
steer = err * -2.0;`

Object Detection & Color Following

The HuskyLens detects color markers (red/green/pink) to guide navigation.

Depending on detected color, the robot adjusts target_x and recalculates steering offset.

Obstacle Avoidance

If front distance is too small, the robot backs up and turns away.

If objects block the side, the robot makes corrective steering maneuvers.

Parking & Completion

After a set number of detections (count >= 12), the robot executes a parking routine using gyro and ToF feedback.

## Global Variables

Some of the key global variables in the code:

| Variable Name | Type | Purpose |
| --- | ---- | --- |
| yaw | float | Stores gyro yaw angle |
| frontdist, leftdist, rightdist | int | Stores ToF distance readings |
| target_X | int | Takes the sum of the correctional values of red, green and pink |
| count | int | Counts laps based of each 90 degree turn |
| side | int | Defines direction (1 = counter-clockwise, 2 = clockwise) |
| red, green, pink | float | They are float correction value calculated from the blocks x and y position, used to steer the robot toward alignment when the marker is off center.| 

## Example: Forward Movement with Gyro Correction

`gyro.update();
yaw = gyro.getYaw();
rightdist = constrain(right.readDistance1(), 0, 1200);
leftdist = constrain(left.readDistance1(), 0, 1200);
forward(yaw, target_x, rightdist, leftdist);
`
This ensures that the robot drives forward while correcting its heading using the gyroscope and wall distances.

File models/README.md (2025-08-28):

Models
====

This directory contains all the custom 3D models used for our robot. The chassis is a fully optimized, super small design with sharp servo steering, while additional sensor mounts were created in Tinkercad. The rear assembly is adapted to work with LEGO wheels, axles, and a reinforced differential. Below is a table of our 3D-printed parts and their functions. (The iterations of the robot, how all the electrical components and 3d models fit with robot and the purpose and optimization of each piece will be described in BUILD)

| File Name | Description | Image |
| --- | --- | --- |
| spur_gear_36t.stl | To transfer power from the 6V motors to the modified LEGO differential, we designed and 3D-printed a 36-tooth gear that fits the motor’s 3mm D-shaped shaft and meshes with the LEGO axle system. Using a 36-tooth input gear with a 24-tooth output gear, we geared it for higher speed because the motor has a low RPM and high torque. |  |
| Final_Diff.stl | The LEGO differential was imported from an online CAD model into SolidWorks, then slightly reinforced by adding extra material around the mounting holes and adapted to fit our custom chassis. These modifications improve durability while maintaining smooth power transfer to the wheels under high-torque operation. |  |
| Chassis_Model.stl | The chassis is a fully optimized, custom-designed base modeled in SolidWorks for a compact structure with sharp servo steering. It houses the drivetrain, electronics, and reinforced LEGO differential, forming the core of the robot. For details on iterations, component placement, and assembly, see the build documentation. |  |
| Steering_Connecting_Bar.stl | The steering connecting bar is a compact, custom-designed link optimized for the sharp servo steering system of the WRO Future Engineers self-driving car. Modeled in SolidWorks, it features recessed screw inlets that improve grip and durability, ensuring a secure fit while transferring motion smoothly between steering components. Its minimal, lightweight design makes it both efficient and reliable under high steering loads. |  |
| wheelholder.stl | The wheel holder was custom-designed in SolidWorks for our compact steering system. The extended cylinder secures a bearing for smooth tire rotation, while the smaller hole connects to the steering bar and the larger hole mounts to the chassis base. |  |
| FINAL_DS_HOLDER.stl | A custom-made, imported 4M LEGO beam is combined with a secure holder, modeled in TinkerCAD to keep the TOF sensor rigid and immovable. The holder eliminates any shifting or vibration, ensuring consistent and accurate sensor readings. Its LEGO integration allows for straightforward attachment to the structure while maintaining a locked, stable position. |  |

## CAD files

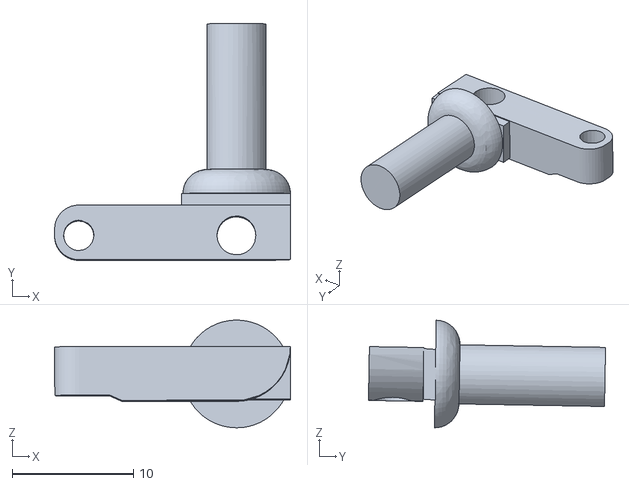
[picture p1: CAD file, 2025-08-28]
models/wheelholderleft.stl
19.5 x 19.5 x 8.87

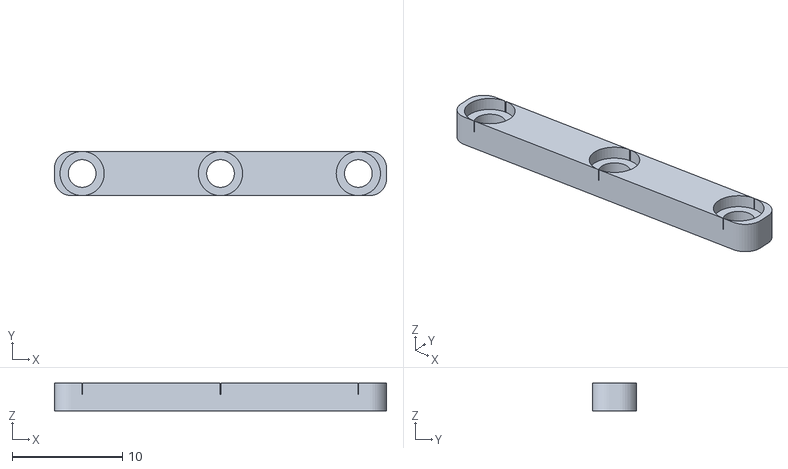
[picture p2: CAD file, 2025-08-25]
models/Steering_Connecting_Bar.stl
30.0 x 4.00 x 2.50

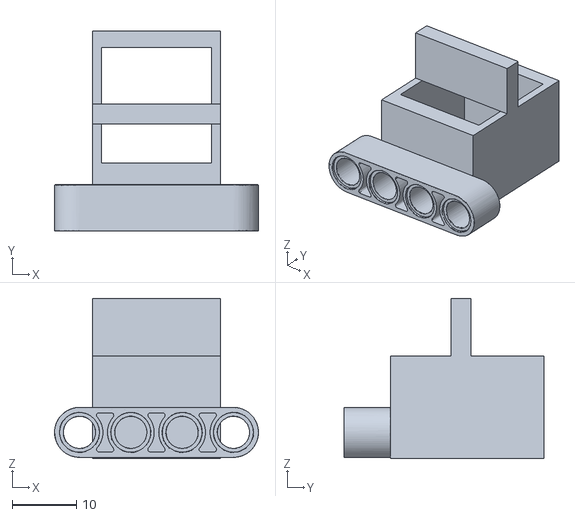
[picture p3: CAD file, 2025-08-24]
models/FINAL_DS_HOLDER.stl
31.8 x 31.2 x 25.0

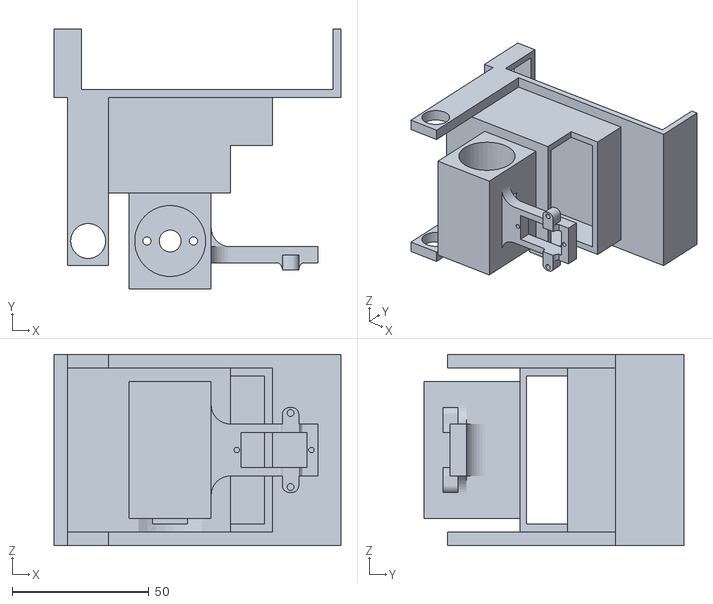
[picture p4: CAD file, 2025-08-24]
models/Chassis_Model.STL
105.0 x 95.0 x 70.0

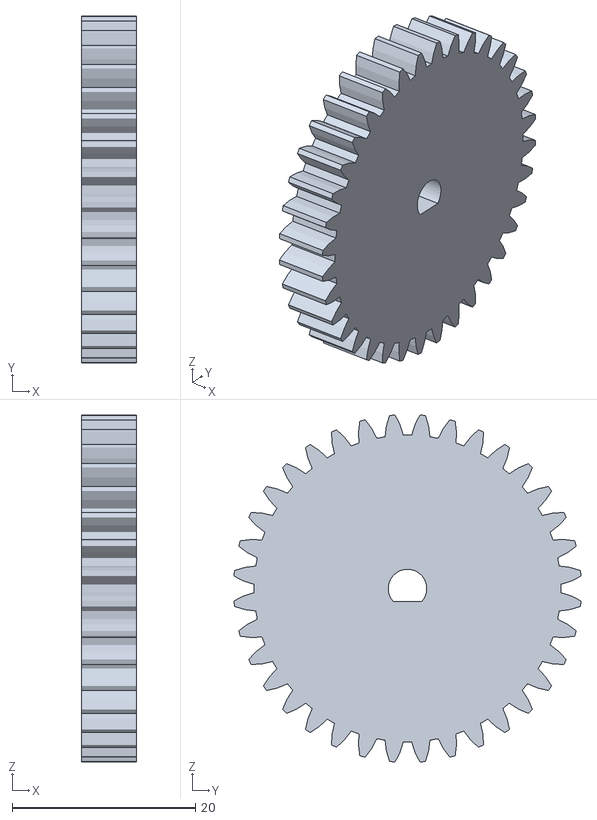
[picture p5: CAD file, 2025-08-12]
models/spur_gear_36t.STL
6.00 x 37.9 x 37.9

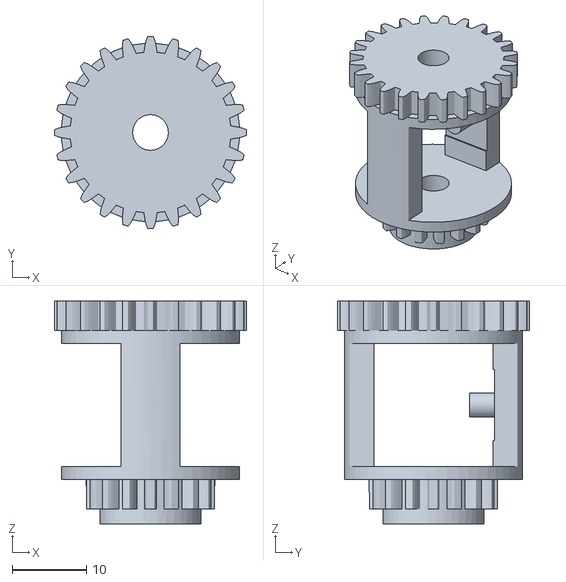
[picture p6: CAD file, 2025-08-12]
models/Final_Diff.STL
25.9 x 25.9 x 30.0

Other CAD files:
models/wheelholderright.stl

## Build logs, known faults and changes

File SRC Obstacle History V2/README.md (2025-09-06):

This directory has all of our codes and iterations of our newest car.

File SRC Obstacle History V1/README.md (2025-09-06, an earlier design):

This directory has all of our codes and iterations of our oldest car.

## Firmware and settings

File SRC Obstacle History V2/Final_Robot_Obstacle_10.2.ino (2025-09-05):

#include <SMotor.h>
#include <ESP32Servo.h>
#include <ZebraTOF.h>
#include <ZebraGyro.h>
#include "Wire.h"
#include "HUSKYLENS.h"
SMotor motor(1);
bool flag = false;
Servo myservo;
int servoPin = 27;
ZebraGyro gyro(7, 12);
ZebraTOF front(5);
ZebraTOF right(4);
ZebraTOF left(3);
int target_x = 0;
float offsetangle = 0;
const int buttonPin = 15;
int i = 0;
float kp = 0.8;        // GYRO PROPORTIONAL
bool distance = true;  //DISTANCE PROPORTIONAL BOOLEAN
int count = 0;
int side = 0;  // (1:left turn, 2:right turn)
int target = 0;
int rightdist = 0;
int leftdist = 0;
int frontdist = 0;
#define enc 17
float yaw = 0;
int angle = 0;
unsigned long turned = -2000;




float lwallval = 0;
float rwallval = 0;

float red = 0;
float green = 0;
float pink = 0;
int rx = 0;
int ry = 0;
int gx = 0;
int gy = 0;
int by = 0;
int bx = 0;
int ox = 0;
int oy = 0;
int px = 0;
int py = 0;

bool gp = false;
bool rp = false;
bool bl = false;
bool ol = false;
bool pw = false;

bool wallval = true;

int baseSpeed = 80;
int motorSpeed = 60;
int curr_y = 0;

int rw = 0;
int rh = 0;
int ra = 0;
int gw = 0;
int gh = 0;
int ga = 0;

HUSKYLENS huskylens;
HardwareSerial mySerial(2);
#define HUSKYLENS_RX 4
#define HUSKYLENS_TX 0
bool pillar = false;
void setup() {
  // initialize device
  Serial.begin(115200);
  Wire.begin();
  motor.run_motor(0, 0);
  //initialize everything
  front.begin();
  right.begin();
  left.begin();
  gyro.begin();
  pinMode(enc, INPUT_PULLUP);
  attachInterrupt(digitalPinToInterrupt(enc), wheel_pulse, RISING);
  ESP32PWM::allocateTimer(0);
  ESP32PWM::allocateTimer(1);
  ESP32PWM::allocateTimer(2);
  ESP32PWM::allocateTimer(3);
  myservo.setPeriodHertz(50);  // standard 50 hz servo

  myservo.attach(servoPin, 500, 2500);
  pinMode(2, OUTPUT);
  digitalWrite(2, HIGH);

  mySerial.begin(9600, SERIAL_8N1, HUSKYLENS_RX, HUSKYLENS_TX);
  while (!huskylens.begin(mySerial)) {
    Serial.println(F("Begin failed!"));
    Serial.println(F("1. Recheck HUSKYLENS Protocol (should be Serial 9600)"));
    Serial.println(F("2. Recheck wiring: Blue wire to RX, Green wire to TX"));
    delay(1000);
  }
  // configure LED for output
  int buttonState = digitalRead(buttonPin);

  while (buttonState == 1) {
    buttonState = digitalRead(buttonPin);
  }
  delay(200);
  // Parrallel Exit
  rightdist = constrain(right.readDistance1(), 0, 1200);  //RIGHT
  leftdist = constrain(left.readDistance1(), 0, 1200);    //LEFT
  if (rightdist < leftdist) {

    side = 1;  //left
    target = abs(offsetangle) + 75;
    gyro.update();
    yaw = gyro.getYaw();
    motor.run_motor(1, 50);
    while (yaw > (target * -1)) {
      gyro.update();
      yaw = gyro.getYaw();
      myservo.write(45);
    }
    motor.stop_motor();
    camread();
    delay(500);
    if (rp == true && ry > gy) {
      target = abs(offsetangle);
      gyro.update();
      yaw = gyro.getYaw();
      motor.run_motor(1, 55);
      while (yaw < target) {
        gyro.update();
        yaw = gyro.getYaw();
        myservo.write(132);
      }
      motor.stop_motor();
    } else {
      myservo.write(95);
      frontdist = front.readDistance1();
      offsetangle -= 90;
      while (frontdist > 350) {
        frontdist = front.readDistance1();
        gyro.update();
        yaw = gyro.getYaw();
        forward(yaw, 0, 1000, 1000);
      }
      motor.stop_motor();
      offsetangle += 90;
      ////
      target = abs(offsetangle) - 10;
      gyro.update();
      yaw = gyro.getYaw();
      motor.run_motor(1, 55);
      while (yaw < target) {
        gyro.update();
        yaw = gyro.getYaw();
        myservo.write(135);
      }
      motor.stop_motor();
    }
  } else {

    side = 2;  //right
    target = abs(offsetangle) + 50;
    gyro.update();
    yaw = gyro.getYaw();
    motor.run_motor(1, 50);
    while (yaw < target) {
      gyro.update();
      yaw = gyro.getYaw();
      myservo.write(135);
    }
    motor.stop_motor();
    myservo.write(95);
    camread();
    if (rp == true) {
      frontdist = front.readDistance1();
      offsetangle += 90;
      while (frontdist > 250) {
        frontdist = front.readDistance1();
        gyro.update();
        yaw = gyro.getYaw();
        forward(yaw, 0, 1000, 1000);
      }
      motor.stop_motor();
      offsetangle -= 90;
    } else {
      motor.run_motor(1, 60);
      delay(500);
      motor.stop_motor();
    }
    target = abs(offsetangle) + 15;
    gyro.update();
    yaw = gyro.getYaw();
    motor.run_motor(1, 60);
    while (yaw > target) {
      gyro.update();
      yaw = gyro.getYaw();
      myservo.write(55);
    }
    motor.stop_motor();
    myservo.write(95);
  }
}
void loop() {

  //////////////

  camread();
  if (ra > ga) {
    red = 0.003 * (20 - rx) * ry;  //0.005
    green = 0;
    curr_y = ry;
  } else if (ga > ra) {
    green = 0.003 * (280 - gx) * gy;  //0.004
    red = 0;
    curr_y = gy;
  }
  if (pw) {
    distance = false;
    if (side == 1) {
      if (py > gy) {
        pink = 0.0037 * (270 - px) * py;
        green = 0.0004 * (280 - gx) * gy;
      } else {
        pink = 0.0004 * (270 - px) * py;
        green = 0.003 * (280 - gx) * gy;
      }
    } else {
      if (py > ry) {
        pink = 0.0037 * (30 - px) * py;
        red = 0.0004 * (20 - rx) * ry;
      } else {
        pink = 0.0004 * (30 - px) * py;
        red = 0.003 * (20 - rx) * ry;
      }
    }
  } else {
    distance = true;
  }
  if (by > gy && by > ry && side == 1 && bx > rx && bx > gx && (millis() - turned > 4000)) {
    green = 0;
    red = 0;
    curr_y = 0;
  }

  if (oy > gy && oy > ry && side == 2 && ox < rx && ox < gx && (millis() - turned > 4000)) {
    green = 0;
    red = 0;
    curr_y = 0;
  }

  motorSpeed = baseSpeed - int((0.4 * curr_y));  //70 and 0.2
  if (by > 100 && side == 1) {
    motorSpeed = 45;
  } else if (oy > 100 && side == 2) {
    motorSpeed = 45;
  }
  if (motorSpeed < 45) {
    motorSpeed = 45;
  }
  target_x = green + red + pink;


  gyro.update();
  yaw = gyro.getYaw();
  rightdist = constrain(right.readDistance1(), 0, 1200);  //RIGHT
  leftdist = constrain(left.readDistance1(), 0, 1200);    //LEFT

  if (gp == true) {
    rightdist = 1000;
  } else if (rp == true) {
    leftdist = 1000;
  }
  if (rightdist < 100) {
    myservo.write(70);
    motor.run_motor(1, 56);

  } else if (leftdist < 100) {
    myservo.write(125);
    motor.run_motor(1, 56);
  } else {
    // gyro.update();
    forward(yaw, target_x, rightdist, leftdist);
  }


  if (bl == true && by > 170 && side == 1 && (millis() - turned > 4000)) {  ////by > 140 && bx > 140
    // motor.stop_motor();
    count += 1;
    if (count >= 13) {
      park();
    }
    camread();
    leftdist = constrain(left.readDistance1(), 0, 1200);
    // motor.run_motor(1, 55);
    if (gp == true) {
      // motor.stop_motor();
      // delay(100);
      motor.run_motor(1, 45);
      if (leftdist < 300) {
        target = abs(offsetangle) + 30;
        while (yaw > (target * -1)) {
          gyro.update();
          yaw = gyro.getYaw();
          myservo.write(85);
        }
      } else {
        target = abs(offsetangle) + 60;
        while (yaw > (target * -1)) {
          gyro.update();
          yaw = gyro.getYaw();
          myservo.write(65);
        }
      }
      // motor.stop_motor();
    } else if (rp == true) {
      i = 0;
      while (i < 450) {
        gyro.update();
        yaw = gyro.getYaw();
        frontdist = constrain(front.readDistance1(), 0, 1200);
        leftdist = 1000;
        rightdist = 1000;
        target_x = 0;
        forward(yaw, target_x, rightdist, leftdist);
      }
      frontdist = constrain(front.readDistance1(), 0, 1200);
      while (frontdist > 270) {
        gyro.update();
        yaw = gyro.getYaw();
        frontdist = constrain(front.readDistance1(), 0, 1200);
        leftdist = 1000;
        rightdist = 1000;
        target_x = 0;
        forward(yaw, target_x, rightdist, leftdist);
      }
      // motor.stop_motor();
      ////
      motor.run_motor(1, 45);
      target = abs(offsetangle) + 50;
      while (yaw > target * -1) {
        gyro.update();
        yaw = gyro.getYaw();
        myservo.write(55);
      }
      // motor.stop_motor();
    } else {
      frontdist = constrain(front.readDistance1(), 0, 1200);
      while (frontdist > 450) {
        gyro.update();
        yaw = gyro.getYaw();
        frontdist = constrain(front.readDistance1(), 0, 1200);
        leftdist = 1000;
        rightdist = 1000;
        target_x = 0;
        forward(yaw, target_x, rightdist, leftdist);
      }
      // motor.stop_motor();

      ////
      motor.run_motor(1, 45);
      target = abs(offsetangle) + 75;
      while (yaw > (target * -1)) {
        gyro.update();
        yaw = gyro.getYaw();
        myservo.write(45);
      }
      motor.stop_motor();

      myservo.write(95);
      motor.run_motor(0, 55);
      delay(750);
      motor.stop_motor();
    }
    myservo.write(95);
    distance = true;
    // wallval = true;
    i = 0;
    offsetangle -= 88;
    turned = millis();
  }

  if (ol == true && oy > 170 && side == 2 && (millis() - turned > 4000)) {
    // motor.stop_motor();
    count += 1;
    if (count >= 13) {
      park2();
    }
    camread();
    rightdist = constrain(right.readDistance1(), 0, 1200);  //RIGHT
    if (rp == true) {
      // motor.stop_motor();
      // delay(100);
      motor.run_motor(1, 45);
      if (rightdist < 300) {
        target = abs(offsetangle) + 40;
        while (yaw < target) {
          gyro.update();
          yaw = gyro.getYaw();
          myservo.write(115);
        }
      } else {
        target = abs(offsetangle) + 38;
        while (yaw < target) {
          gyro.update();
          yaw = gyro.getYaw();
          myservo.write(135);
        }
      }
      // motor.stop_motor();

    } else if (gp == true) {
      i = 0;
      while (i < 450) {
        gyro.update();
        yaw = gyro.getYaw();
        frontdist = constrain(front.readDistance1(), 0, 1200);
        leftdist = 1000;
        rightdist = 1000;
        target_x = 0;
        forward(yaw, target_x, rightdist, leftdist);
      }
      frontdist = constrain(front.readDistance1(), 0, 1200);
      while (frontdist > 350) {
        gyro.update();
        yaw = gyro.getYaw();
        frontdist = constrain(front.readDistance1(), 0, 1200);
        leftdist = 1000;
        rightdist = 1000;
        target_x = 0;
        forward(yaw, target_x, rightdist, leftdist);
      }
      // motor.stop_motor();
      ////
      motor.run_motor(1, 45);
      target = abs(offsetangle) + 70;
      while (yaw < target) {
        gyro.update();
        yaw = gyro.getYaw();
        myservo.write(135);
      }
      // motor.stop_motor();
    } else {
      frontdist = constrain(front.readDistance1(), 0, 1200);
      while (frontdist > 450) {
        gyro.update();
        yaw = gyro.getYaw();
        frontdist = constrain(front.readDistance1(), 0, 1200);
        leftdist = 1000;
        rightdist = 1000;
        target_x = 0;
        forward(yaw, target_x, rightdist, leftdist);
      }
      // motor.stop_motor();
      ////
      motor.run_motor(1, 45);
      target = abs(offsetangle) + 75;
      while (yaw < target) {
        gyro.update();
        yaw = gyro.getYaw();
        myservo.write(145);
      }
      motor.stop_motor();
      myservo.write(95);
      motor.run_motor(0, 55);
      delay(750);
      motor.stop_motor();
    }
    myservo.write(95);
    distance = true;
    // wallval = true;
    i = 0;
    offsetangle += 90;
    turned = millis();
  }
}


void forward(float g, float block, int rwd, int lwd) {
  if (rwd < 250) {
    rwallval = 0.15 * (rwd - 250);
  } else {
    rwallval = 0;
  }
  if (lwd < 300) {
    lwallval = 0.2 * (lwd - 300);
  } else {
    lwallval = 0;
  }

  kp = 0.5;
  /////
  if (millis() - turned < 2500) {
    kp = 0.2;
  }

  angle = (int)(kp * (g - (offsetangle - block)));
  int pos = 95 - angle;
  pos = constrain(pos, 65, 115);
  myservo.write(pos);
  motor.run_motor(1, motorSpeed);
}

void rforwardwall(float g, int d) {  // what is r forward? write some comment about it.
  float wallval = 0.2 * (d - 150);
  angle = int(0.6 * (g - (offsetangle + wallval)));
  int pos = 95 - angle;
  pos = constrain(pos, 85, 105);
  myservo.write(pos);
  motor.run_motor(1, 60);
}

void lforwardwall(float g, int d) {
  float wallval = 0.2 * (d - 200);
  angle = int(0.8 * (g - (offsetangle - wallval)));
  int pos = 95 - angle;
  pos = constrain(pos, 85, 105);
  myservo.write(pos);
  motor.run_motor(1, 60);
}

void wheel_pulse() {
  // Optional encoder logic if needed

  i++;
}
void camread() {
  huskylens.request();
  rw = 0;
  rh = 0;
  ra = 0;
  gw = 0;
  gh = 0;
  ga = 0;
  ry = 0;
  rx = 0;
  gx = 0;
  gy = 0;
  bx = 0;
  by = 0;
  ox = 0;
  oy = 0;
  px = 0;
  py = 0;
  bl = false;
  ol = false;
  gp = false;
  rp = false;
  pw = false;
  if (!huskylens.available()) {
    target_x = 0;
    wallval = true;
    pillar = true;
    bl = false;
    ol = false;
    gp = false;
    rp = false;
    pw = false;

  } else {
    while (huskylens.available()) {
      HUSKYLENSResult result = huskylens.read();
      if (result.command == COMMAND_RETURN_BLOCK) {

        if (result.ID == 1) {  //result.yCenter > 50
          rp = true;
          rx = result.xCenter;
          ry = result.yCenter;  // red → turn left
          rw = result.width;
          rh = result.height;
          ra = rx * rh;
          // red = 0.018 * (20 - result.xCenter) * result.yCenter;
          // pillar = false;
          // wallval = false;


        }
        // else {
        //   rp = false;
        //   rx = 0;
        //   ry = 0;
        //   red = 0;
        // }
        else if (result.ID == 2) {  //
          gp = true;
          gx = result.xCenter;
          gy = result.yCenter;  // green → turn right
          gw = result.width;
          gh = result.height;
          ga = gw * gh;
          // green = 0.018 * (280 - result.xCenter) * result.yCenter;
          // pillar = false;
          // wallval = false;
        }
        //  else {
        //   gp = false;
        //   gx = 0;
        //   gy = 0;
        //   green = 0;
        // }
        else if (result.ID == 3) {
          ol = true;
          ox = result.xCenter;
          oy = result.yCenter;
        }
        // else {
        //   ox = 0;
        //   oy = 0;
        //   ol = false;
        // }
        else if (result.ID == 4) {
          bl = true;
          bx = result.xCenter;
          by = result.yCenter;
        }
        // else {
        //   bx = 0;
        //   by = 0;
        //   bl = false;
        // }

        else if (result.ID == 5) {
          pw = true;
          px = result.xCenter;
          py = result.yCenter;
        }
        // else {
        //   pw = false;
        //   px = 0;
        //   py = 0;
        //   pink = 0;
        // }
      }
    }
  }
}


void park2() {
  motor.run_motor(1, 60);  ////turn left
  target = abs(offsetangle) - 80;
  while (yaw > target) {
    gyro.update();
    yaw = gyro.getYaw();
    myservo.write(45);
  }
  motor.stop_motor();
  myservo.write(95);
  offsetangle -= 88;
  frontdist = constrain(front.readDistance1(), 0, 1200);
  while (frontdist > 200) {
    gyro.update();
    yaw = gyro.getYaw();
    frontdist = constrain(front.readDistance1(), 0, 1200);
    leftdist = 1000;
    rightdist = 1000;
    target_x = 0;
    forward(yaw, target_x, rightdist, leftdist);
  }
  motor.stop_motor();
  myservo.write(95);
  // delay(1000);
  motor.run_motor(1, 60);  ////turn left
  target = abs(offsetangle) - 80;
  while (yaw > target) {
    gyro.update();
    yaw = gyro.getYaw();
    myservo.write(45);
  }
  motor.stop_motor();
  myservo.write(95);
  offsetangle -= 88;
  ////////
  gyro.update();
  yaw = gyro.getYaw();
  frontdist = constrain(front.readDistance1(), 0, 1200);
  while (frontdist > 300) {
    gyro.update();
    yaw = gyro.getYaw();
    frontdist = constrain(front.readDistance1(), 0, 1200);
    rightdist = constrain(right.readDistance1(), 0, 1200);  //RIGHT
    rforwardwall(yaw, rightdist);
  }
  motor.stop_motor();
  motor.run_motor(1, 60);  ////turn left
  target = abs(offsetangle) - 45;
  while (yaw > target) {
    gyro.update();
    yaw = gyro.getYaw();
    myservo.write(75);
  }
  motor.stop_motor();

  motor.run_motor(1, 45);  ///straighten
  target = abs(offsetangle) + 20;
  while (yaw < target) {
    gyro.update();
    yaw = gyro.getYaw();
    myservo.write(125);
  }
  motor.stop_motor();
  myservo.write(95);
  motor.run_motor(1, 55);
  delay(200);
  motor.stop_motor();
  /////
  rightdist = constrain(right.readDistance1(), 0, 1200);
  while (rightdist > 150) {
    rightdist = constrain(right.readDistance1(), 0, 1200);  //RIGHT
    gyro.update();
    yaw = gyro.getYaw();
    forward(yaw, 0, 1000, 1000);
  }
  motor.stop_motor();
  /////
  ///////////////
  rightdist = constrain(right.readDistance1(), 0, 1200);
  if (rightdist < 300) {     ////logic if close
    motor.run_motor(0, 45);  ///left turn backwards
    target = abs(offsetangle) - 80;
    while (yaw > target) {
      gyro.update();
      yaw = gyro.getYaw();
      myservo.write(150);
    }
    motor.stop_motor();
    myservo.write(95);
    motor.run_motor(0, 45);
    target = abs(offsetangle) + 24;  //right turn forwards
    while (yaw < target) {
      gyro.update();
      yaw = gyro.getYaw();
      myservo.write(40);
    }
    motor.stop_motor();
    myservo.write(95);
    delay(100000000000000);
  } else {
    motor.run_motor(0, 45);
    target = abs(offsetangle) - 80;
    while (yaw > target) {
      gyro.update();
      yaw = gyro.getYaw();
      myservo.write(150);
    }
    motor.stop_motor();
    myservo.write(95);
    motor.run_motor(0, 45);
    delay(400);
    motor.stop_motor();
    ////
    motor.run_motor(0, 45);  //right turn forwards
    target = abs(offsetangle) + 24;
    while (yaw < target) {
      gyro.update();
      yaw = gyro.getYaw();
      myservo.write(40);
    }
    motor.stop_motor();
    myservo.write(95);
    delay(100000000000000);
  }
}





//////////
void park() {
  motor.run_motor(1, 60);
  target = abs(offsetangle) - 65;  ///right turn
  while (yaw < (target * -1)) {
    gyro.update();
    yaw = gyro.getYaw();
    myservo.write(130);
  }
  motor.stop_motor();
  myservo.write(95);
  motor.run_motor(0, 60);
  delay(1000);
  motor.stop_motor();
  /////////
  ////////
  myservo.write(95);
  offsetangle += 88;
  frontdist = constrain(front.readDistance1(), 0, 1200);
  while (frontdist > 200) {
    gyro.update();
    yaw = gyro.getYaw();
    frontdist = constrain(front.readDistance1(), 0, 1200);
    leftdist = 1000;
    rightdist = 1000;
    target_x = 0;
    forward(yaw, target_x, rightdist, leftdist);
  }
  motor.stop_motor();
  delay(1000);
  ///////////
  motor.run_motor(1, 45);
  target = abs(offsetangle) - 70;
  while (yaw < (target * -1)) {
    gyro.update();
    yaw = gyro.getYaw();
    myservo.write(150);
  }
  motor.stop_motor();
  offsetangle += 89;
  gyro.update();
  yaw = gyro.getYaw();
  frontdist = constrain(front.readDistance1(), 0, 1200);
  while (frontdist > 300) {
    gyro.update();
    yaw = gyro.getYaw();
    frontdist = constrain(front.readDistance1(), 0, 1200);
    leftdist = constrain(left.readDistance1(), 0, 1200);  //RIGHT
    lforwardwall(yaw, leftdist);
  }
  motor.stop_motor();
  ////turn right little
  motor.run_motor(1, 45);
  target = abs(offsetangle) - 55;
  while (yaw < (target * -1)) {
    gyro.update();
    yaw = gyro.getYaw();
    myservo.write(125);
  }
  motor.stop_motor();
  ////turn left (straighten)
  motor.run_motor(1, 45);
  target = abs(offsetangle);
  while (yaw > (target * -1)) {
    gyro.update();
    yaw = gyro.getYaw();
    myservo.write(65);
  }
  motor.stop_motor();
  myservo.write(95);
  /////forward until pink wall
  leftdist = constrain(left.readDistance1(), 0, 1200);
  while (leftdist > 150) {
    leftdist = constrain(left.readDistance1(), 0, 1200);  //RIGHT
    gyro.update();
    yaw = gyro.getYaw();
    forward(yaw, 0, 1000, 1000);
  }
  motor.stop_motor();
  /////////
  leftdist = constrain(left.readDistance1(), 0, 1200);
  if (leftdist < 300) {
    motor.run_motor(0, 45);
    target = abs(offsetangle) - 80;
    while (yaw < (target * -1)) {  ///right turn
      gyro.update();
      yaw = gyro.getYaw();
      myservo.write(60);
    }
    motor.stop_motor();
    myservo.write(95);
    ////
    motor.run_motor(0, 45);
    target = abs(offsetangle);
    while (yaw > (target * -1)) {
      gyro.update();
      yaw = gyro.getYaw();
      myservo.write(150);
    }
    motor.stop_motor();
    myservo.write(95);
    delay(100000000000000);
    ////////////////
  } else {
    motor.run_motor(0, 45);
    target = abs(offsetangle) + 80;
    while (yaw < (target * -1)) {
      gyro.update();
      yaw = gyro.getYaw();
      myservo.write(60);
    }
    motor.stop_motor();
    myservo.write(95);
    motor.run_motor(0, 55);
    delay(200);
    motor.stop_motor();
    ////
    motor.run_motor(0, 45);
    delay(100);
    motor.run_motor(0, 45);
    target = abs(offsetangle) + 10;  // -5
    while (yaw > target) {
      gyro.update();
      yaw = gyro.getYaw();
      myservo.write(150);
    }
    motor.stop_motor();
    myservo.write(95);
    delay(100000000000000);
  }
}

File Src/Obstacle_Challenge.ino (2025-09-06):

#include <SMotor.h>           // Motor driver library to control drive motors
#include <ESP32Servo.h>       // Servo control library for ESP32
#include <ZebraTOF.h>         // Time-of-Flight distance sensor library
#include <ZebraGyro.h>        // Gyroscope sensor library
#include "Wire.h"             // I2C communication library, used by sensors
#include "HUSKYLENS.h"        // HuskyLens AI vision sensor library

// Initialize motor instance on motor channel 1
SMotor motor(1);

bool flag = false;            // Generic flag used later?

Servo myservo;                // Steering servo object
int servoPin = 27;            // Pin connected to servo signal

// Initialize gyro with SDA and SCL pins (7 and 12)
ZebraGyro gyro(7, 12);

// Initialize front, right, and left distance sensors (TOF)
ZebraTOF front(5);
ZebraTOF right(4);
ZebraTOF left(3);

int target_x = 0;             // Target x position for steering corrections
float offsetangle = 0;        // Heading offset for gyro corrections

const int buttonPin = 15;     // Pin connected to start button
int i = 0;                   // Encoder pulse counter

// Proportional gain for gyro PID correction
float kp = 0.8;               

bool distance = true;         // Boolean to switch distance-based proportional control

int count = 0;                // Counts number of obstacles passed

int side = 0;                // Side selected for wall following: 1=left, 2=right

int target = 0;               // Target angle for turning or gyro reference

// Variables to store distance readings from sensors
int rightdist = 0;
int leftdist = 0;
int frontdist = 0;

#define enc 17               // Encoder input pin

float yaw = 0;                // Current yaw angle measured by gyro
int angle = 0;                // Steering angle correction value
unsigned long turned = -2000; // Time tracker for last turn event (initialize negative)

// Variables for wall following values
float lwallval = 0;
float rwallval = 0;

// Variables for detected colored objects from camera
float red = 0;
float green = 0;
float pink = 0;

int rx = 0;                  // Red x center
int ry = 0;                  // Red y center
int gx = 0;                  // Green x center
int gy = 0;                  // Green y center
int by = 0;                  // Blue y center
int bx = 0;                  // Blue x center
int ox = 0;                  // Orange x center
int oy = 0;                  // Orange y center
int px = 0;                  // Pink x center
int py = 0;                  // Pink y center

// Booleans to indicate if particular color objects are detected
bool gp = false;             // Green present
bool rp = false;             // Red present
bool bl = false;             // Blue present
bool ol = false;             // Orange present
bool pw = false;             // Pink present

bool wallval = true;         // Flag related to wall detection?

// Motor speed variables
int baseSpeed = 70;          // Base motor speed
int motorSpeed = 60;         // Current motor speed (may be adjusted)

// Current y coordinate of detected object
int curr_y = 0;

// Additional width, height and area variables for detected objects (used with HuskyLens)
int rw = 0;
int rh = 0;
int ra = 0;
int gw = 0;
int gh = 0;
int ga = 0;

// Create HuskyLens camera object
HUSKYLENS huskylens;

// Define serial communication for HuskyLens using UART2
HardwareSerial mySerial(2);

#define HUSKYLENS_RX 4       // HuskyLens RX pin (to ESP32 TX)
#define HUSKYLENS_TX 0       // HuskyLens TX pin (to ESP32 RX)

bool pillar = false;          // Flag to indicate detected pillar?

// Setup function - runs once at startup
void setup() {
  Serial.begin(115200);       // Start serial communication for debug output
  Wire.begin();               // Start I2C bus for sensors

  motor.run_motor(0, 0);      // Ensure motor stopped initially

  // Initialize distance sensors and gyro
  front.begin();
  right.begin();
  left.begin();
  gyro.begin();

  pinMode(enc, INPUT_PULLUP); // Setup encoder pin input with pullup resistor

  // Attach interrupt to encoder pin, call wheel_pulse on rising edge
  attachInterrupt(digitalPinToInterrupt(enc), wheel_pulse, RISING);

  // Allocate PWM timers for 4 channels (for servo control)
  ESP32PWM::allocateTimer(0);
  ESP32PWM::allocateTimer(1);
  ESP32PWM::allocateTimer(2);
  ESP32PWM::allocateTimer(3);

  myservo.setPeriodHertz(50);           // Set servo refresh rate to 50Hz (standard)
  myservo.attach(servoPin, 500, 2500);  // Attach servo with pulse width limits (500-2500us)

  pinMode(2, OUTPUT);                    // Pin 2 output (likely status LED or motor control)
  digitalWrite(2, HIGH);                 // Set pin 2 HIGH

  // Initialize HuskyLens serial communication at 9600 baud
  mySerial.begin(9600, SERIAL_8N1, HUSKYLENS_RX, HUSKYLENS_TX);
  
  // Wait until HuskyLens sensor initializes properly
  while (!huskylens.begin(mySerial)) {
    Serial.println(F("Begin failed!"));
    Serial.println(F("1. Recheck HUSKYLENS Protocol (should be Serial 9600)"));
    Serial.println(F("2. Recheck wiring: Blue wire to RX, Green wire to TX"));
    delay(1000);
  }

  // Initialize button state variable
  int buttonState = digitalRead(buttonPin);

  // Wait for button press (state==0) to start operation
  while (buttonState == 1) {
    buttonState = digitalRead(buttonPin);
  }
  delay(200); // Debounce delay

  // Determine closer wall and decide which side to follow
  rightdist = constrain(right.readDistance1(), 0, 1200);  // Get right distance
  leftdist = constrain(left.readDistance1(), 0, 1200);    // Get left distance

  if (rightdist < leftdist) {  // Closer to right wall
    side = 1;                  // Set side to 1 = left wall follow logic
    target = abs(offsetangle) + 75;

    gyro.update();
    yaw = gyro.getYaw();

    motor.run_motor(1, 50);    // Run motors forward at speed 50

    // Turn left until yaw past target angle on negative scale
    while (yaw > (target * -1)) {
      gyro.update();
      yaw = gyro.getYaw();
      myservo.write(45);       // Set servo to turn wheels left
    }

    motor.stop_motor();        // Stop motors for camera reading

    camread();                 // Read vision sensor to detect objects
    delay(500);

    if (rp == true && ry > gy) {
      // If red object detected and red y > green y, turn right back to initial offset
      target = abs(offsetangle);
      gyro.update();
      yaw = gyro.getYaw();

      motor.run_motor(1, 55);

      while (yaw < target) {
        gyro.update();
        yaw = gyro.getYaw();
        myservo.write(132);     // Steering right
      }

      motor.stop_motor();

    } else {
      // Otherwise move forward until front obstacle detected closer than 350 mm
      myservo.write(95);        // Center steering
      frontdist = front.readDistance1();
      offsetangle -= 90;        // Adjust heading offset left by 90 degrees
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

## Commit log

2025-06-21 Create WRO FE June 2025 Arduino Code
2025-06-21 Update WRO FE June 2025 Arduino Code
